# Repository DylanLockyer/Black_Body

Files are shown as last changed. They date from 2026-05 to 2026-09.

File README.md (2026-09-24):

# Black Body Controller
[USER MANUAL](Documentation/README.md)

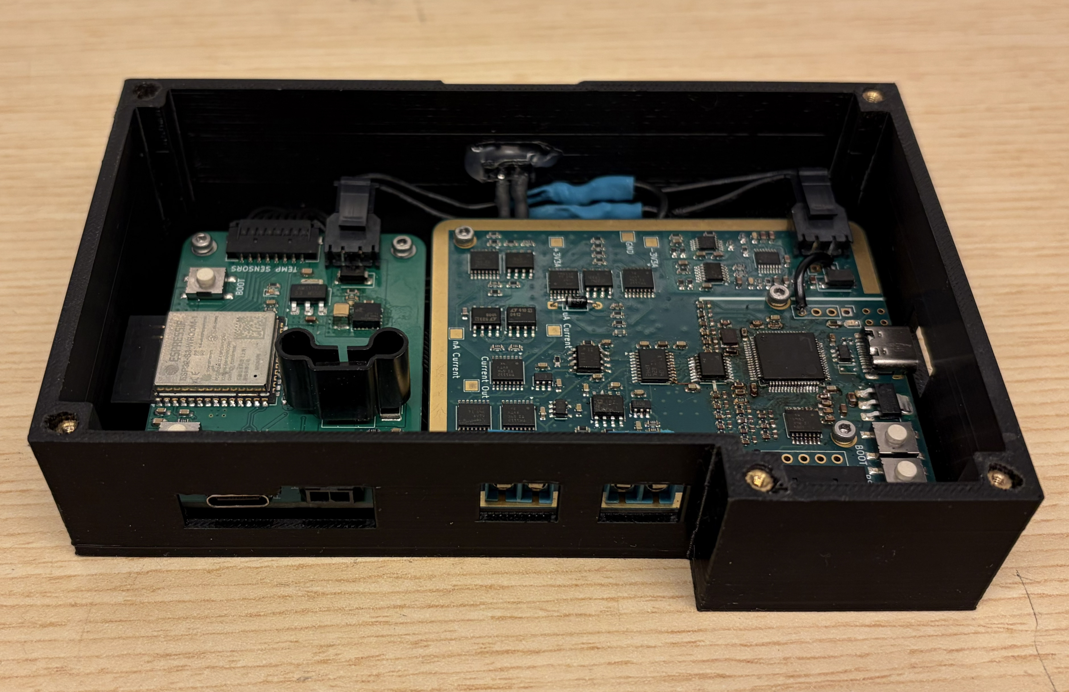
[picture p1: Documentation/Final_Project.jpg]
Measure tab

## Overview
This project controls and monitors a black body heater module mounted to the 4K stage of a cryostat. It is split into two custom PCBs: a heater control board built around an ESP32 (current source, voltage/current sensing, PID control, and a self-hosted web interface) and a temperature sensor board built around an STM32G4 for reading from a germanium temperature sensor for ranges from 0.3 to 100 kelvin (high-precision, low-noise excitation and readout for temperature probes). The two boards communicate over SPI, with the ESP32 acting as the master controller and network-facing interface.

## Project Goals
- Heat the black body module (4x 10Ω heaters in series, 40Ω equivalent) from the cryostat's 4K stage to temperatures above 80K, with closed-loop PID control.
- Accurately measure temperature across the cryogenic range using a Germanium RTD (LakeShore GR-300-AA).
- Provide low-noise, precisely switchable current excitation (10nA to 1mA) and high-resolution (24-bit) voltage/current measurement for sensor readout.
- Expose a self-hosted web interface (over WiFi) for live monitoring and control of both heating and measurement, with no external software required.

## Documentation
- [Heater Control PCB](Circuit%20Boards/Black_Body_Heater_Control_PCB/README.md) — heater current source, voltage/current sensing, and power supply design.
- [Temperature Sensor PCB](Circuit%20Boards/Black_Body_Temperature_Sensor_PCB/README.md) — sensor excitation, precision measurement, and isolation design.
- [ESP32 Firmware](Firmware/ESP32_heater/README.md) — heater PID control, SPI link to the sensor board, and the web interface.
- [STM32 Firmware](Firmware/stm32_black_body/README.md) — sensor excitation control, ADC readout, and the SPI link to the ESP32.
- [Device Usage Guide](Documentation/README.md) — how to power up, connect to, and operate the device.

## Repository Organization
**Circuit Boards:** KiCad source files and manufacturing/gerber files for both PCBs.

**Firmware:** ESP32 (PlatformIO) heater control firmware and STM32 (STM32CubeIDE) sensor readout firmware.

**Documentation:** Images, schematics, and the device usage guide.

**Simulations:** LTspice and PSpice simulations used to validate circuit designs before ordering.

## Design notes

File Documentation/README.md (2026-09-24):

# Device Usage Guide

How to power up, connect to, and operate the black body controller. For hardware/firmware design details, see the [root README](../README.md) and its links.

## Getting Started

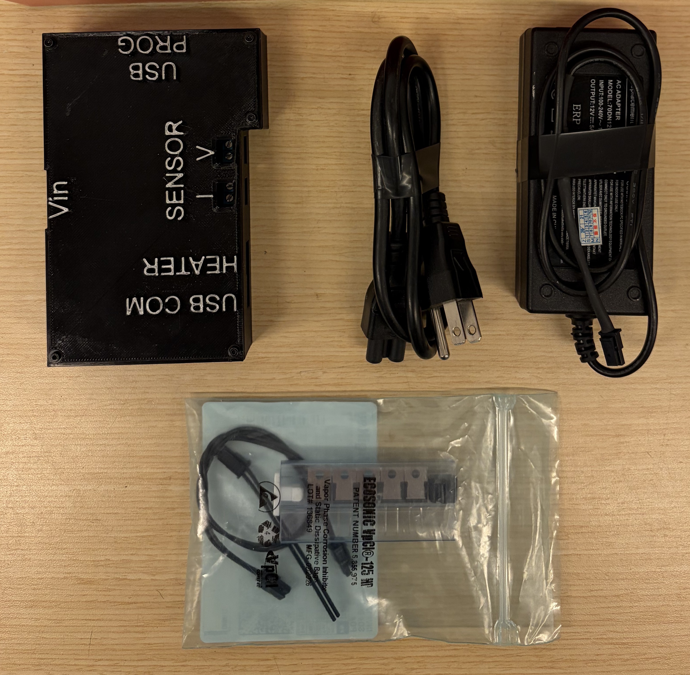
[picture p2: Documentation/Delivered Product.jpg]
Delivered Product


The delivered unit is the 3D-printed enclosure (containing both PCBs), a 12V AC power adapter with mains cable, and a bag with the temperature probes and cables.

The enclosure has five connections on its edges:

| Label | Purpose |
|---|---|
| **Vin** | 12V DC input from the included power adapter |
| **SENSOR — I / V** | 4-wire connection to the germanium temperature probe: the **I** terminals carry the excitation current, the **V** terminals are the voltage sense leads |
| **HEATER** | The resistive heater element (max 12V/0.5A) |
| **USB COM** | USB port to the ESP32 heater/control board |
| **USB PROG** | USB port to the STM32 sensor board |

Before powering on, connect the temperature probe to **SENSOR** (I and V screw terminals) using the probe's datasheet to match pinout and the heater to **HEATER**, then plug the power adapter's output into **Vin**. The USB ports are only needed when reprogramming the firmware (see [Programming](#programming)) — they aren't used for normal operation. For the first power up after delivery it is recommended to use a resistor connected via 4 wire kelvin sensing to the Sensor I/V to ensure it wasn't damaged in transit.

## Powering On

Plug the adapter into mains power. There is no separate power switch — connecting mains power turns the unit on, and unplugging it turns it off. On power-up, the ESP32 begins broadcasting its WiFi access point and the STM32 sensor board starts pushing resistance/voltage/current readings to it over SPI; the readings become live in the web interface within a few seconds.

## Connecting to the Device

The controller hosts its own WiFi network — it does not join your existing WiFi. Connect to the access point:

- **Network name:** `Black Body`
- **Password:** none (open network)

Most phones and laptops will detect the captive portal and open the control page automatically. If it doesn't pop up, open a browser and go to:

```
http://192.168.4.1/
```

## Using the Web Interface

### Measure

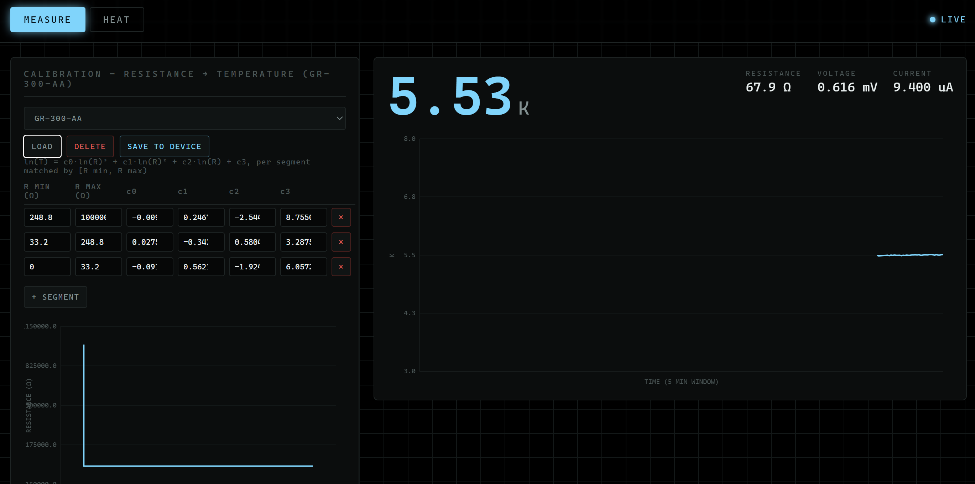
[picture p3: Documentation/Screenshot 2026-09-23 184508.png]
Measure tab


The left panel manages calibration **profiles** for the connected sensor: the default profile for the GR-300AA is automatically loaded. To pick a different saved profile, select it from the dropdown and use **LOAD** to make it active, **SAVE TO DEVICE** to store the currently-edited segments under a name, or **DELETE** to remove a saved profile. The segment table below it defines the resistance-to-temperature curve as a set of piecewise cubic segments (see [Calibration](#calibration) for how these are generated); use **+ SEGMENT** to add a row. The **DEBUG** panel (click **SHOW**) exposes the current excitation level, current direction, active shunt resistor, whether the calibration is valid, and which profile is currently active.

The right panel shows the live reading: temperature in large text, with resistance, voltage, and current underneath, plus a rolling 5-minute chart.

### Heat

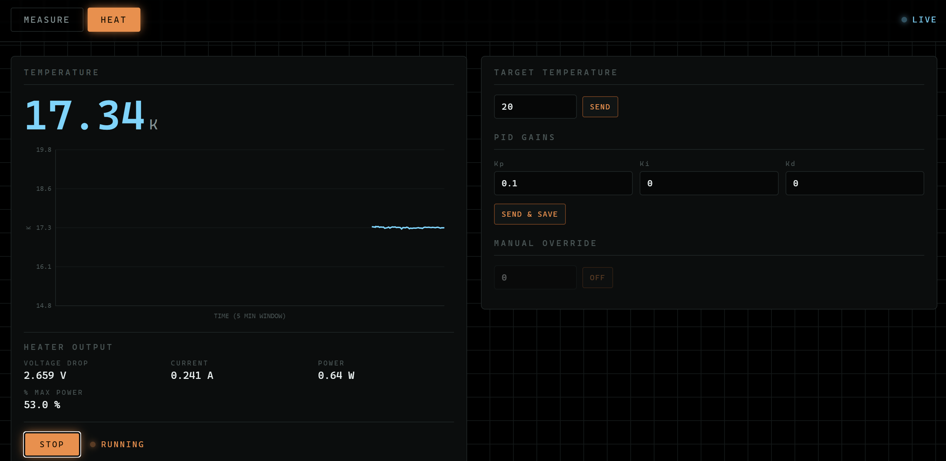
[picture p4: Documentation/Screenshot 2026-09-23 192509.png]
Heat tab


The left panel shows live temperature and a chart, plus a heater output readout (voltage drop, current, power, and percent of max power), and the **START/STOP** button that enables or disables closed-loop control.

The right panel sets the **target temperature** (sent with **SEND**) and the **PID gains** Kp/Ki/Kd (sent and saved to flash with **SEND & SAVE**). A **manual override** lets you drive the heater at a fixed current (0–0.5A) instead of running PID for testing which only works while the PID loop is stopped; the device will reject it otherwise.

## Calibration

Calibration profiles map measured sensor resistance to temperature as piecewise cubic segments of the form:

```
ln(T) = c0·ln(R)³ + c1·ln(R)² + c2·ln(R) + c3
```

with each segment applying over its own `[R min, R max)` range.

There are two ways to get the data for a new profile:

- **From the sensor's datasheet:** most calibrated sensors, including LakeShore probes, come with a resistance-vs-temperature table or published fit coefficients for that specific sensor. Use those values as the (resistance, temperature) pairs in step 3 below and skip the measurement steps. If the datasheet already gives piecewise fit coefficients in the same `ln(T)` vs `ln(R)` form, you can enter them directly (step 4).
- **By measuring the sensor yourself:** follow all the steps below.

To build a new profile for a sensor:

1. On the **Measure** tab, read the live resistance value as you take the probe through its usable temperature range (e.g. warming or cooling it slowly while checking its temperature against a reference).
2. Record pairs of (resistance, temperature) at enough points to span the full range you care about.
3. Give this list of resistance/temperature pairs to an AI assistant (e.g. Claude) and ask it to fit the data to the segmented curve form above, i.e. to return the `[R min, R max)` bounds and `c0`–`c3` coefficients for each segment needed to cover your data.
4. Enter the returned segments into the segment table on the Measure tab (use **+ SEGMENT** to add rows), then click **SAVE TO DEVICE** and give the profile a name.
5. Select the new profile from the dropdown and **LOAD** it to make it active.

## Programming

Reflashing either board requires opening the enclosure:

1. Unplug the power adapter, then remove the 5 M2 screws holding the enclosure lid and lift it off to access the boards' USB ports and BOOT/RESET buttons.
2. Reconnect the 12V power supply to **Vin**, and connect a USB cable from your PC to the port for the board you're programming — **USB COM** for the ESP32, **USB PROG** for the STM32.
3. On that board, hold down its **BOOT** button, briefly press and release **RESET**, then release **BOOT**. This forces the microcontroller into its USB bootloader instead of starting the existing firmware.
4. Flash the new firmware:
   - **ESP32** ([`Firmware/ESP32_heater`](../Firmware/ESP32_heater)): build and upload with PlatformIO (`pio run -t upload`, or the Upload button in the PlatformIO IDE). If you changed `data/website.html`, also run `pio run -t uploadfs` to update the web UI stored on the device.
   - **STM32** ([`Firmware/stm32_black_body`](../Firmware/stm32_black_body)): build using stm32 extension for VScode + cmake and flash with STM32CubeProgrammer over the USB PROG connection.
5. Unplug the unit, replace the lid, and reinstall the 5 M2 screws.

## Specifications

| | |
|---|---|
| **Input power** | 12V DC, via included adapter into **Vin** |
| **Heater element** | 4×10Ω in series (40Ω), analog current-source driven (not PWM) |
| **Heater output** | Up to ~12V / 0.3A peak, ~10W max |
| **Heater control** | Closed-loop PID, or manual current override (0–0.5A) while PID is stopped |
| **Sensor excitation current** | 10nA – 1mA DC in six decade steps (10nA, 100nA, 1µA, 10µA, 100µA, 1mA), switchable polarity |
| **Sensor ADC** | 24-bit (ADS131M04) |
| **Supported sensor** | LakeShore GR-300-AA germanium RTD, 4-wire |
| **Temperature range** | 2K – 100K. The GR-300-AA is rated down to 0.3K, but the low-temperature excitation limiting needed below ~2K was never calibrated, so that range is disabled |
| **Wireless interface** | Self-hosted WiFi AP `Black Body` (open), captive portal, `192.168.4.1` |
| **Board-to-board link** | SPI (ESP32 as slave, STM32 as master) |
| **Microcontrollers** | ESP32-S3 (heater/control board), STM32G431 (sensor board) |
| **Programming** | USB COM → ESP32 (PlatformIO), USB PROG → STM32 (STM32CubeProgrammer) |

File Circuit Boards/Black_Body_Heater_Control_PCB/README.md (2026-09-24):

# Black Body Heater Control PCB

Two-layer circuit board carrying the ESP32 microcontroller and all heater control electronics: current source, voltage/current sensing, and power supply. See the [firmware README](../../Firmware/ESP32_heater/README.md) for how this board is driven, and the [root README](../../README.md) for overall project context.

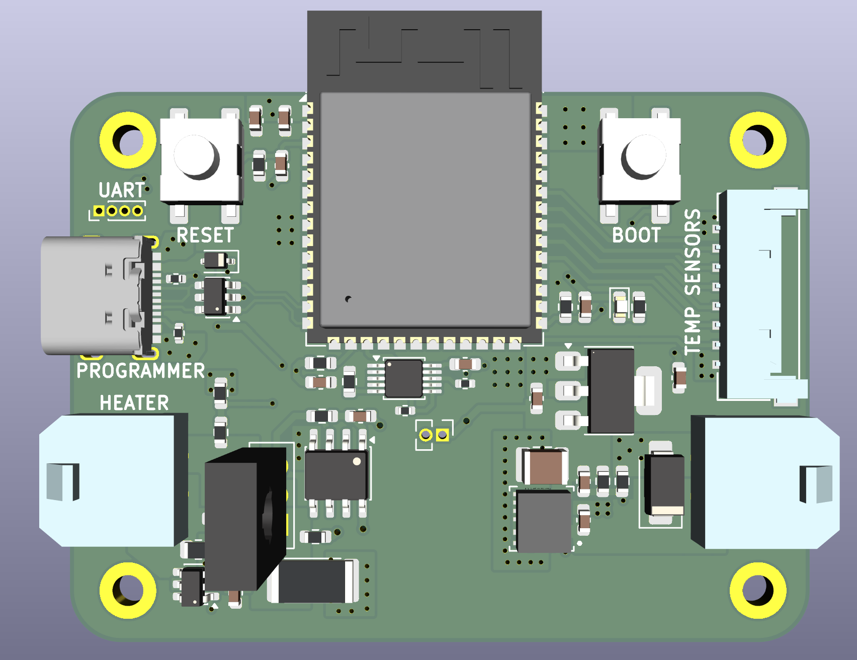
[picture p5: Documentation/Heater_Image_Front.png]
Front

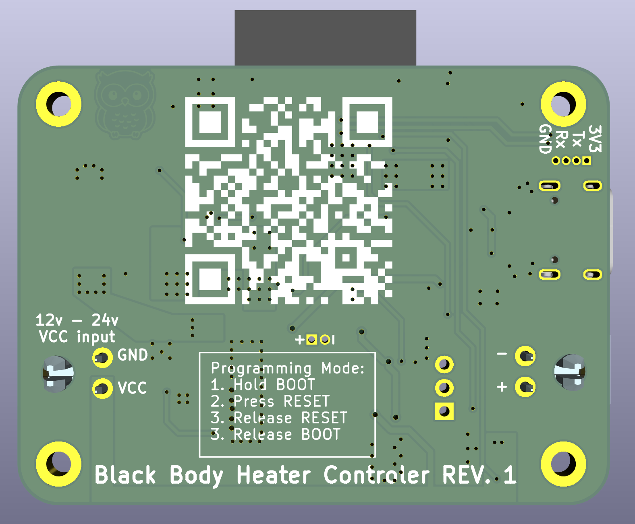
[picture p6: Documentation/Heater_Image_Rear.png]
Rear


Schematic: [Black_Body_Heater_Control_Schematic.pdf](../Black_Body_Heater_Control_Schematic.pdf)

## Microcontroller
An ESP32 was chosen for its high pin count and WiFi support, letting it self-host a web page for displaying readings and controlling the heater. It interfaces with the [temperature sensor board](../Black_Body_Temperature_Sensor_PCB/README.md) over SPI (3 CS lines for 3 temperature probes). The microcontroller is programmed over USB, with exposed pads for UART programming as a fallback. Board-to-board interfacing uses Molex connectors (504050-0891 for the SPI link) since they could be sampled for free.

## Heater Controller
The heater is 4x 10Ω resistors in series (40Ω total). A maximum output power of 10W requires a peak 12V at 0.3A, measured with a shunt resistor + amplifier (current) and a voltage divider (voltage), both read by the ESP32's internal 12-bit ADC. This gives a theoretical current step of 100µA (max 0.66A range) and a voltage step of 8mV (max 36V range).

The original design used an N-channel MOSFET with PWM to control heater voltage. Due to concerns about PWM noise interfering with the sensor board's measurements, this was replaced with an analog current source instead.

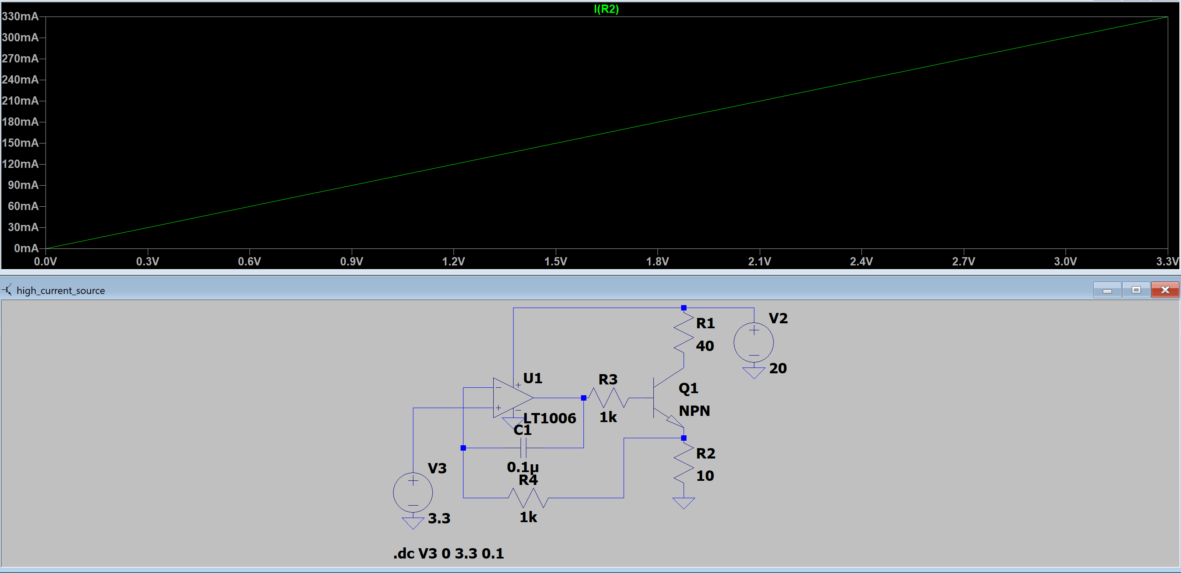
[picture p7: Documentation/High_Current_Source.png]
High Current Source


Output current vs. input voltage for the analog current source. A BJT and op-amp generate the current output, driven by a DAC that the microcontroller controls.

## Shunt Current Measurement
The shunt resistor is 100mΩ with a 50V/V amplifier gain, giving 2.5V output at 0.5A and 0.25V at 0.05A. A low-pass filter on the amplifier output is largely unnecessary now that PWM isn't used, but is kept (with an easy jumper to bypass it) in case it's needed. Simulated filtering of a 10% duty cycle, 10kHz PWM signal on 20V is shown below:

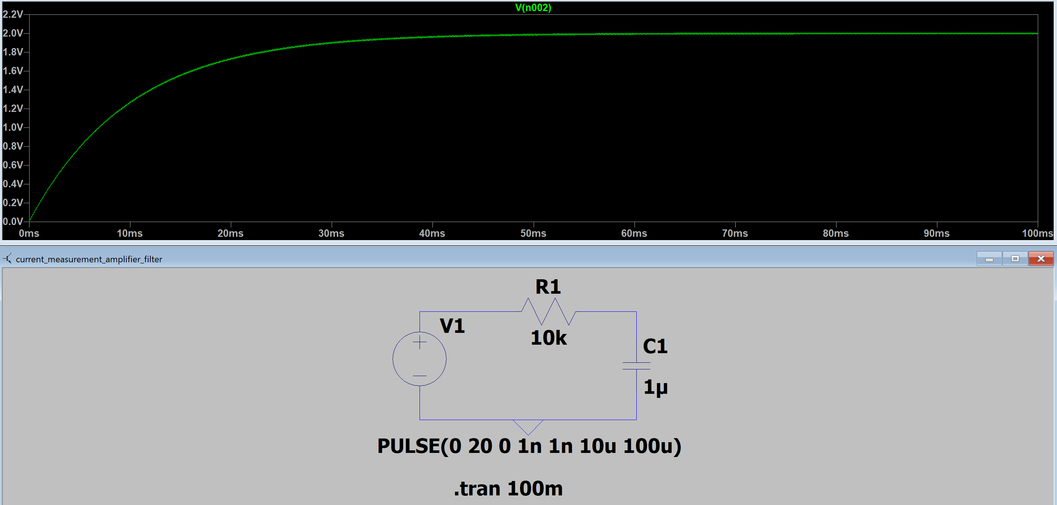
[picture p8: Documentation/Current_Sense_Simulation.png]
Current Sense Simulation


## Power Source
The board receives 12V from an external power supply. A buck converter steps this down to 5V at 2A, followed by an LDO to 3.3V for a clean, low-noise supply to the microcontroller and ADC. \
**Revision 1:** Changed buck converter to newer module as the rev 0 as it broke and fried both boards.

## Simulation
Heater and buck converter behavior were validated in PSpice before layout (see [Simulations/Heater_Controller_PCB](../../Simulations/Heater_Controller_PCB)):

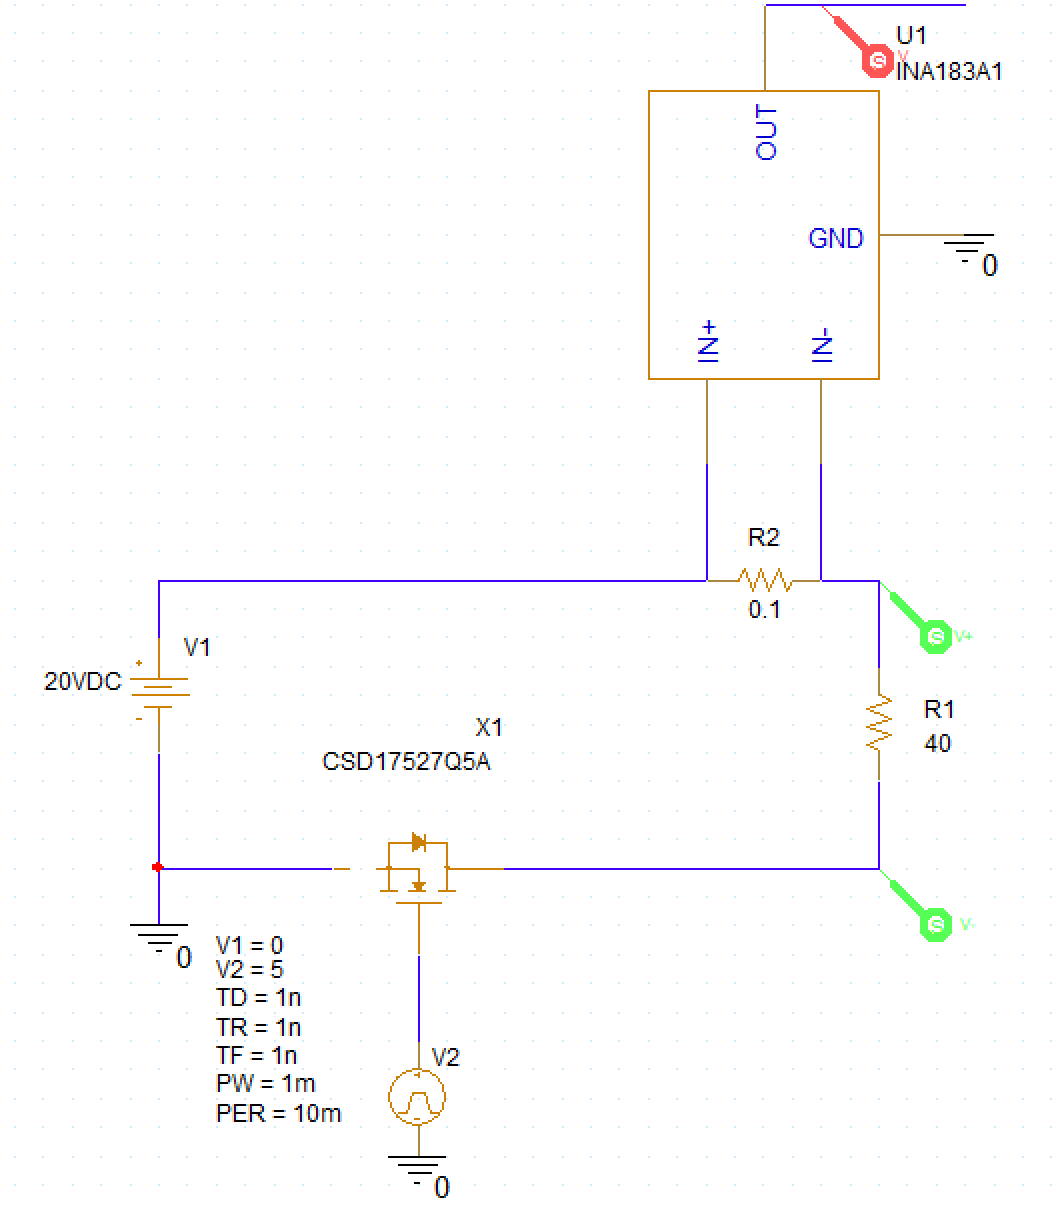
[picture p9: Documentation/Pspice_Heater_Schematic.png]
PSpice Heater Schematic

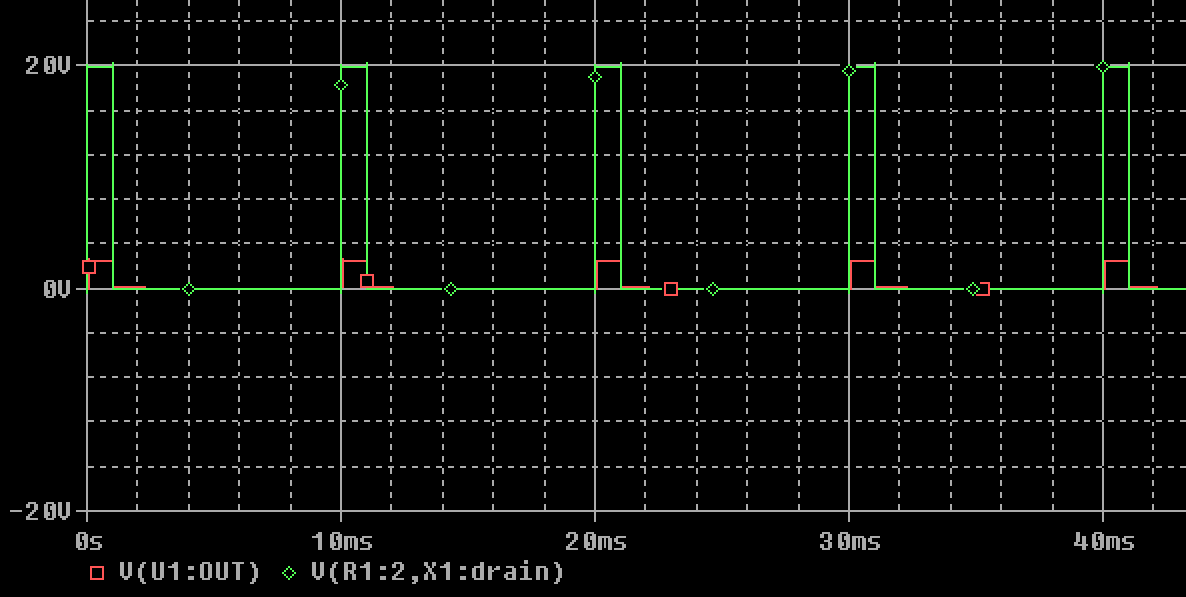
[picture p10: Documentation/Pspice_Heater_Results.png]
PSpice Heater Results


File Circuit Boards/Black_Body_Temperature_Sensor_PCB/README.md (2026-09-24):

# Black Body Temperature Sensor PCB

Six-layer circuit board that reads temperature from Germanium RTD sensors and Silicon diode sensors. See the [firmware README](../../Firmware/stm32_black_body/README.md) for how this board is driven, and the [root README](../../README.md) for overall project context.

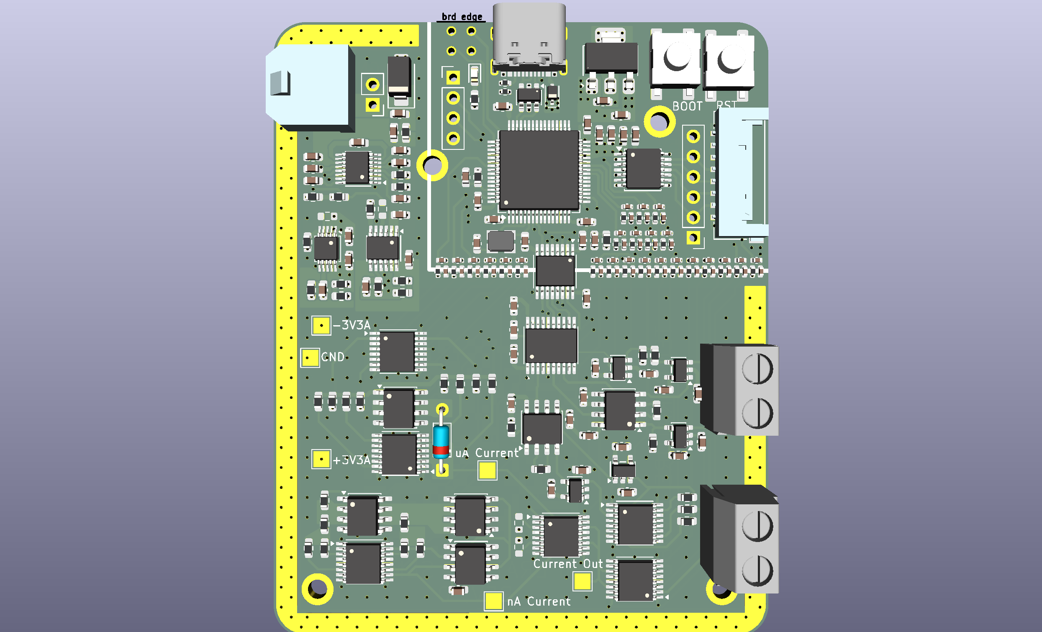
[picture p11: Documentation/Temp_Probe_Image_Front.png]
Front

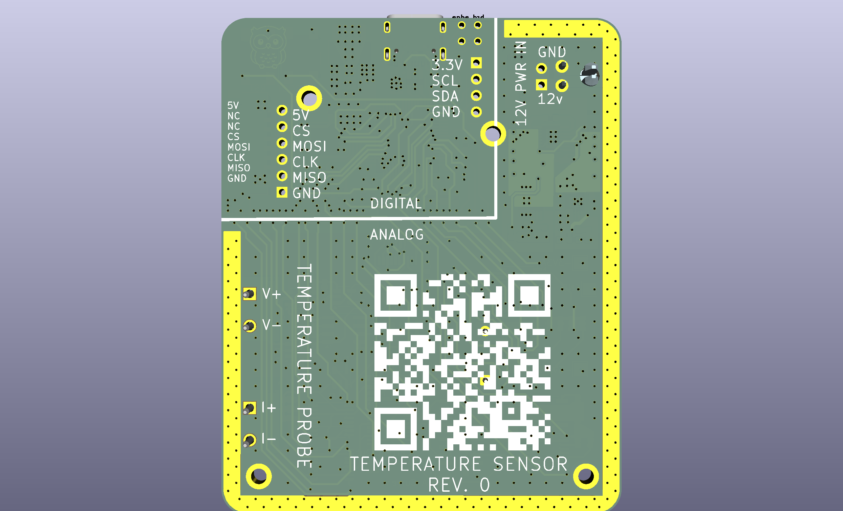
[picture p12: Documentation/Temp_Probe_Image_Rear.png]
Rear


Schematic/board renders: [Black_Body_Temperature_Sensor_Schematic.pdf](../../Documentation/Black_Body_Temperature_Sensor_Schematic.pdf), [Black_Body_Temperature_Sensor_PCB.pdf](../../Documentation/Black_Body_Temperature_Sensor_PCB.pdf)

## Temperature Probe Readers
The board must support both Germanium sensors (LakeShore GR-300-AA) and Silicon diode sensors (LakeShore DT-670A1-CU), which are both 4-wire sensors: current is sourced over 2 wires (I+/I-) and voltage is read over the other 2 (V+/V-) so the voltage drop across the lead wires isn't included in the measurement.

Two LakeShore temperature probe readers were used as reference:

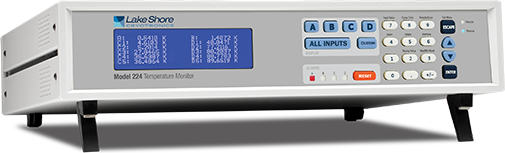
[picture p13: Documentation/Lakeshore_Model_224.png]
Lakeshore Model 224

**Model 224:** Accurate to 0.3K with DC current from 100nA to 1mA. Ability to source both positive and negative current allows EMF voltages to be eliminated.

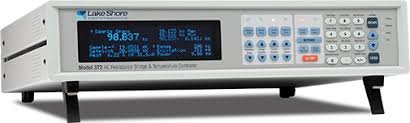
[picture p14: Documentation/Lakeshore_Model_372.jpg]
Lakeshore Model 372

**Model 372:** Accurate to 0.05K with AC current as low as 10pA to eliminate self-heating at extremely low temperatures (power levels in attowatts, 10⁻¹⁸W). Significantly more complex to implement and unnecessary for our sensors, which don't go below 0.3K.

The Model 224 was used as the primary reference since this application won't go below 4K, and it supports almost the full range of the GR-300-AA and the full range of the DT-670A1-CU (down to 1.4K).

## DT-670A1-CU Sensor
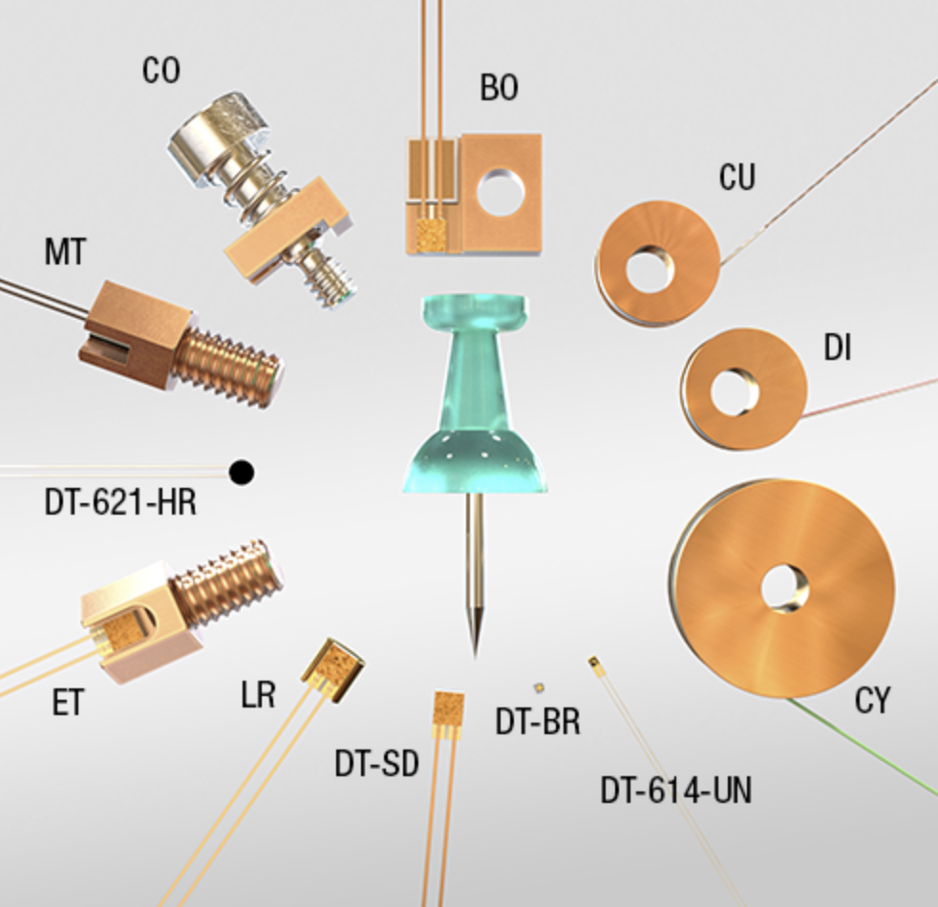
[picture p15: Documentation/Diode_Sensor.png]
Diode Sensor

Silicon diode temperature sensor, 1.4K to 420K range. Requires a constant excitation of 10µA ± 0.1%; the voltage across it ranges from 1.64V at 1.4K to 0.560V at 305K.

## GR-300-AA Sensor
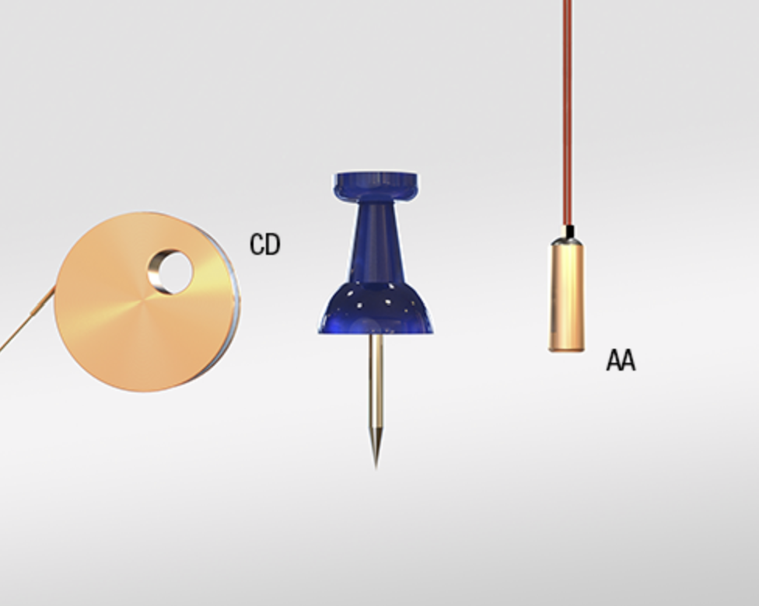
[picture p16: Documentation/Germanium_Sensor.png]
Germanium Sensor

Germanium temperature sensor, 0.3K to 100K range. Resistance varies logarithmically with temperature, from 35180Ω at 0.3K to 2.716Ω at 100K. Below 1K, excitation should be limited (LakeShore recommends 63µV; the Model 224 uses 3600µV at 0.3K to 900µV at 1K) since thermal mass is very small and self-heating matters more. Above 1K, excitation should stay under 10mV; the Model 224 sources 100nA to 1mA to keep the voltage under that limit.

## My Implementation
- Current excitation from 10nA to 1mA, DC, switchable direction.
- High-precision instrumentation amplifier for I+/I- sensor lead current measurement.
- Voltage measurement precise across 1mV to 10mV, since below 1K the signal can't go lower than ~0.9mV (10nA) and above 1K self-heating matters less.
- 24-bit ADC for both current and voltage; galvanic isolation between the digital and analog side is manually bypassed as it was causing issues and the same power supply is used for both digital and analog sides.
- Low-noise, high common-mode-rejection amplifiers to bring small signals up to reasonable voltage levels.

## Clean Voltage Supply
The board takes in a clean +12V, low-pass filtered. An LTC3260 splits the rail into +5V and -5V. The +5V rail is regulated to +3.3V with an LT3042EMSE, and the -5V rail similarly with an LT3094, for extra-clean supplies.

The LTC3260 could not be simulated (a common issue with its SPICE model), but the 3.3V regulator stages were simulated:

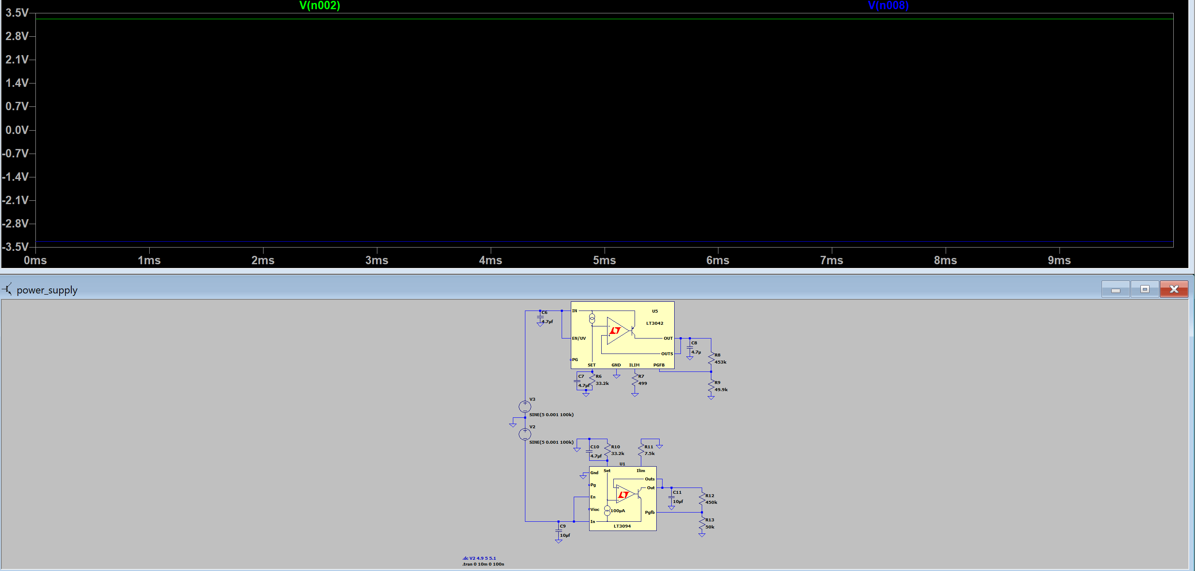
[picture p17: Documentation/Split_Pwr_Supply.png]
Split Power Supply


## Current Sources
Target outputs: 10nA, 100nA, 1µA, 10µA, 100µA, 1mA, split into two circuits (below 1µA and above/equal to 1µA).

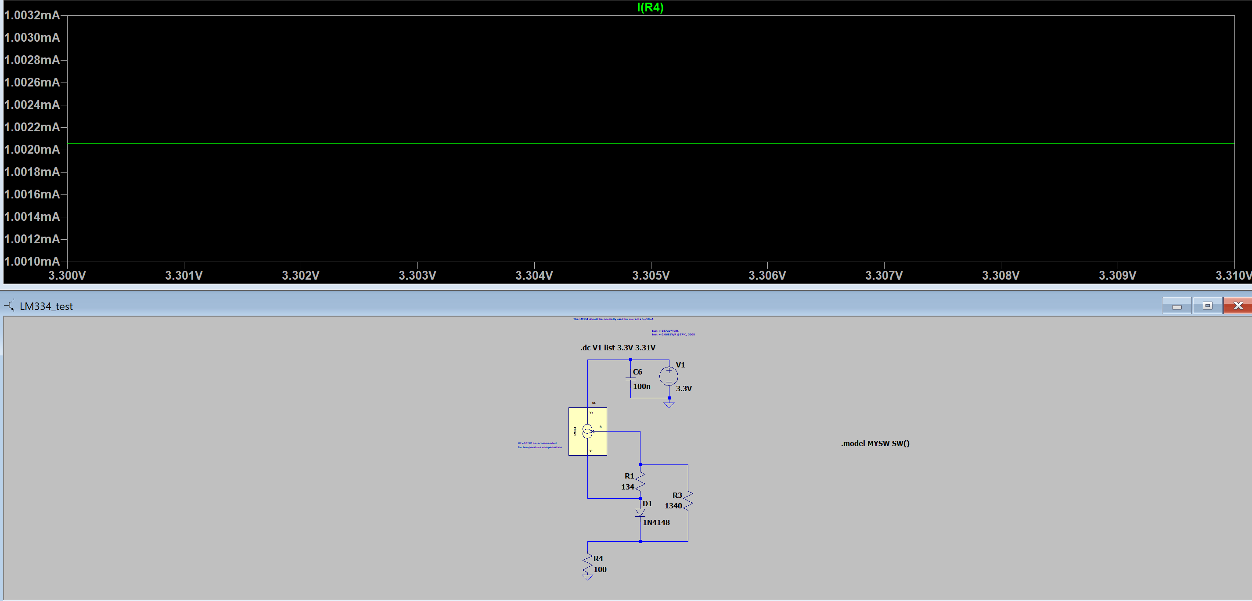
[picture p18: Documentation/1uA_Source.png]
1uA Source

Greater-than-1µA source, using the TI LM334 per its application note. Different current outputs are selected by switching resistors R1 & R3 with high-precision analog switches.

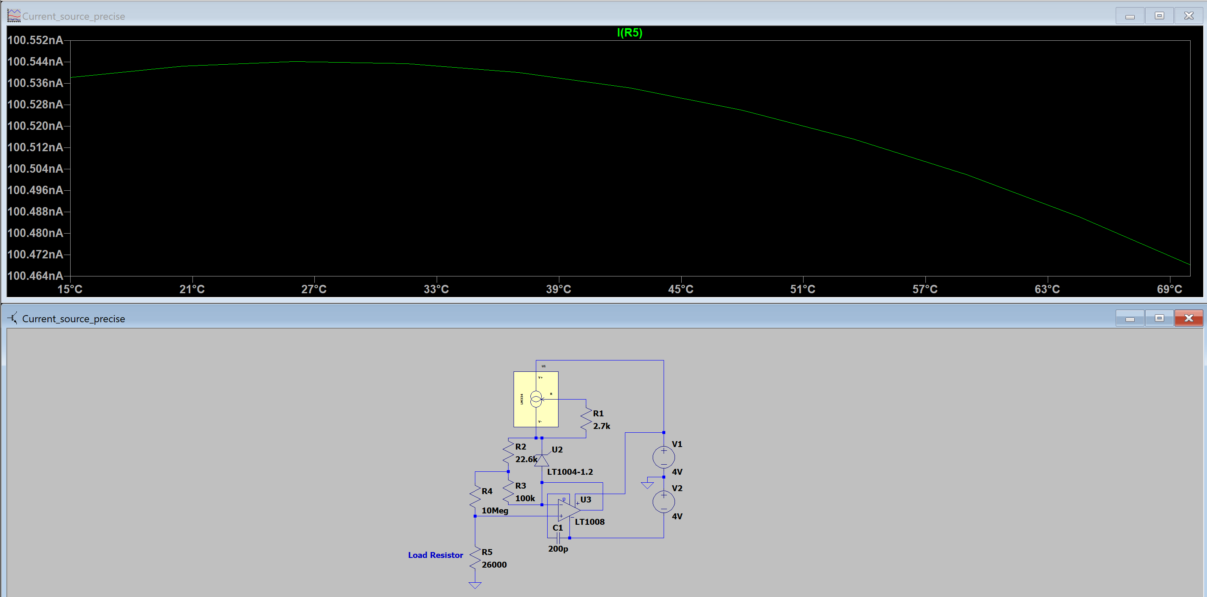
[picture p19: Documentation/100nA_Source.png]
100nA Source

Less-than-1µA source, also using the LM334 but following an Analog Devices example schematic with an instrumentation op-amp to reach the 10nA range (confirmed by simulation). Analog switches again select the current level.

## Voltage Measurement
The Germanium sensors produce 0.5mV to 5mV at the given excitation currents. The signal is buffered by an OPA376 (10pA bias current), then fed to a differential instrumentation amplifier (AD8421ARZ, 200x gain), then into one of the 4 channels of a 24-bit ADC (ADS131M04). The ADC communication is isolated from the microcontroller to keep the analog and digital grounds separate.

## Current Measurement
Measured via the shunt method, using the same voltage-measurement chain to read the voltage drop across a 5Ω, 500Ω, or 33kΩ shunt (selected with analog switches).

## Switching Current Direction
The same analog switches (TMUX1112PWR, 3pA noise injection) reverse current direction between measurements to cancel out EMF voltages induced by dissimilar metals in the sensor leads.

## Digital Section
Built around the STM32G4. It has a 5V-tolerant SPI interface for talking to the [heater control board](../Black_Body_Heater_Control_PCB/README.md), and a USB 2.0 interface for programming and future use with a PC application. Either connection can supply power, with protection against both being connected simultaneously. An I2C breakout is provided for future expansion. All GPIOs driving the analog-section switches pass through a PI filter first to give a slow ramp-up and limit noise:

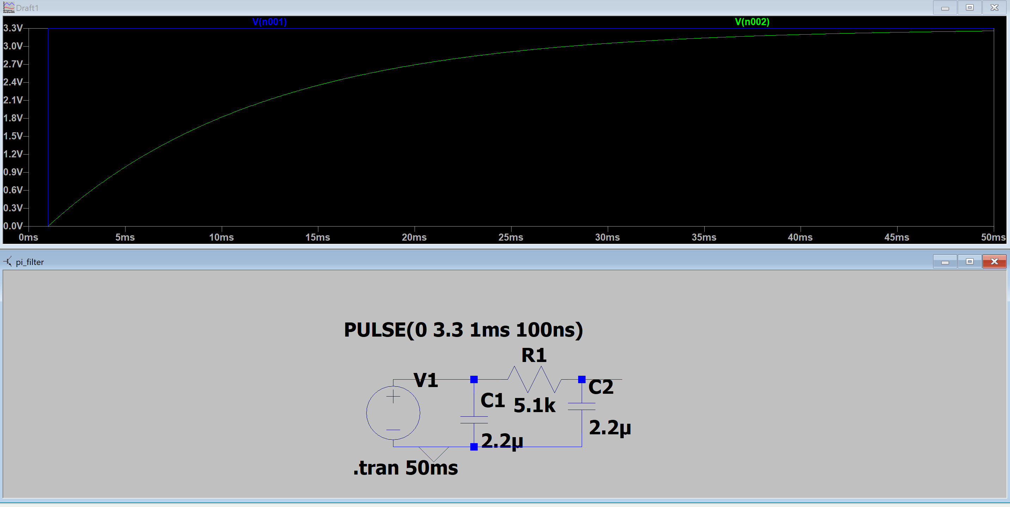
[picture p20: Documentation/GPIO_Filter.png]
GPIO Filter


## Stackup
Six layers, chosen to simplify grounding, with ENIG surface finish:

```
Analog
Gnd
+3.3V
-3.3V
Gnd
Mixed signal
```

The two 3.3V layers also carry small digital 3.3V and GND traces to the analog switches. The bottom layer is primarily digital switch routing, with some small analog jumps.

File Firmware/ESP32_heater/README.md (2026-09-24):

# ESP32 Heater Firmware

Firmware for the [heater control PCB](../../Circuit%20Boards/Black_Body_Heater_Control_PCB/README.md). Built with PlatformIO (Arduino framework for ESP32). This is the "master" of the system: it drives the heater, talks to the STM32 sensor board over SPI, and hosts the web interface used to operate the device — see the [device usage guide](../../Documentation/README.md).

## What It Does
- **WiFi access point + web UI:** Starts a self-hosted WiFi AP (`WiFi.softAP`) with a DNS captive portal and an async web server that serves the control page (`data/website.html`) and a JSON API for live readings and commands.

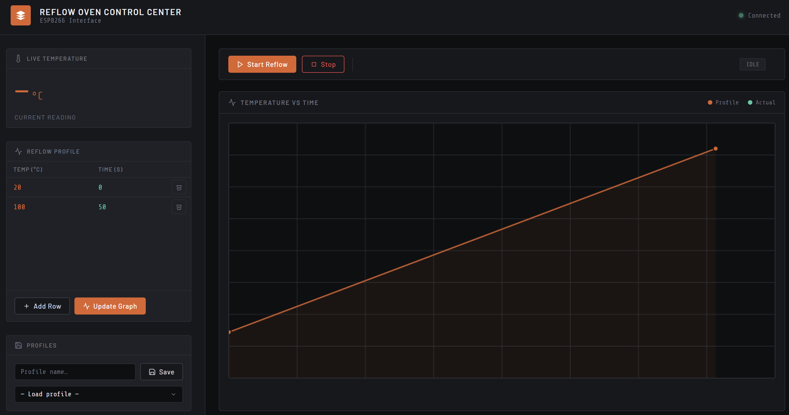
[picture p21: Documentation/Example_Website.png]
Example UI
  

- **Sensor readout over SPI:** Acts as an SPI slave, receiving voltage/current/resistance readings (`STM32Sensor`) pushed by the STM32 sensor board, which drives the SPI clock as master.
- **Resistance → temperature calibration:** Maintains per-sensor calibration "profiles" (piecewise cubic segments mapping resistance to temperature, see `SegmentedCalibration.h`), editable from the web UI and persisted to flash (LittleFS) so no on-device curve fitting is needed.
- **Heater PID control:** Runs a PID loop targeting a user-set temperature, or a manual power override, and drives the heater's analog current source through a DAC (`DAC60501`). PID gains and the active setpoint are persisted to flash.

## Task Structure
The firmware splits work across the ESP32's two cores to keep the SPI link and WiFi stack from blocking each other:
- **Core 0 — `sensorTask`:** Polls the STM32 over SPI as fast as possible and updates the shared reading state under `dataMutex`.
- **Core 1 — `loop()`:** Arduino's main loop, handling only WiFi/DNS captive-portal housekeeping.
- **Core 1 — `heaterTask`:** Runs the PID/manual-override heater control loop at ~5Hz, independent of the networking loop.

## Layout
- `src/main.cpp` — setup, FreeRTOS tasks, PID control, calibration/config persistence.
- `include/main.h` — pin definitions and shared types.
- `data/website.html` — the web UI served to clients connected to the AP.

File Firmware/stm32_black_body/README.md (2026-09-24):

# STM32 Temperature Sensor Firmware

Firmware for the [temperature sensor PCB](../../Circuit%20Boards/Black_Body_Temperature_Sensor_PCB/README.md), targeting an STM32G431. Built with STM32CubeIDE / CMake (STM32CubeMX-generated HAL project). This board does the precision analog work — sourcing current into the sensor and reading it back — and pushes the result to the [ESP32](../ESP32_heater/README.md) for display and control.

## What It Does
- **Current source control:** `change_current()` selects the excitation current level and direction (10nA to 1mA, switchable polarity) by driving the analog switches on the sensor board.
- **External ADC readout:** Reads the 24-bit ADS131M04 ADC over SPI3 whenever its DRDY interrupt fires (`adc_flag`), capturing both the sensor voltage and the shunt voltage (used to derive current) for whichever shunt resistor (5Ω / 500Ω / 33kΩ) is currently selected.
- **Resistance calculation:** Computes sensor resistance from the averaged voltage and current readings (a rolling average smooths ADC noise before the divide).
- **Auto-ranging:** `autoset_current()` checks whether the current reading is in a good range for the selected sensor and switches current level/shunt automatically if not.
- **Push to ESP32:** Sends the latest voltage/current/resistance reading to the ESP32 over SPI2, with this board acting as SPI *master* (the ESP32 is the SPI slave and receives whatever this board clocks out).
- **USB:** USB 2.0 (`MX_USB_PCD_Init`) is used for programming and is reserved for a future PC-side application. Either USB or the ESP32 connector can supply board power, with protection against both being connected at once.
- **I2C:** Broken out for future expansion; unused by the current firmware logic.

## Layout
- `Core/Src/main.c` — peripheral init, the ADC read/current-switching main loop, and the SPI push to the ESP32.
- `Library/External_Interface` — SPI2 send routine used to talk to the ESP32.
- `Library/ADS131M04` — Communicates with SPI to the 24-bit adc.

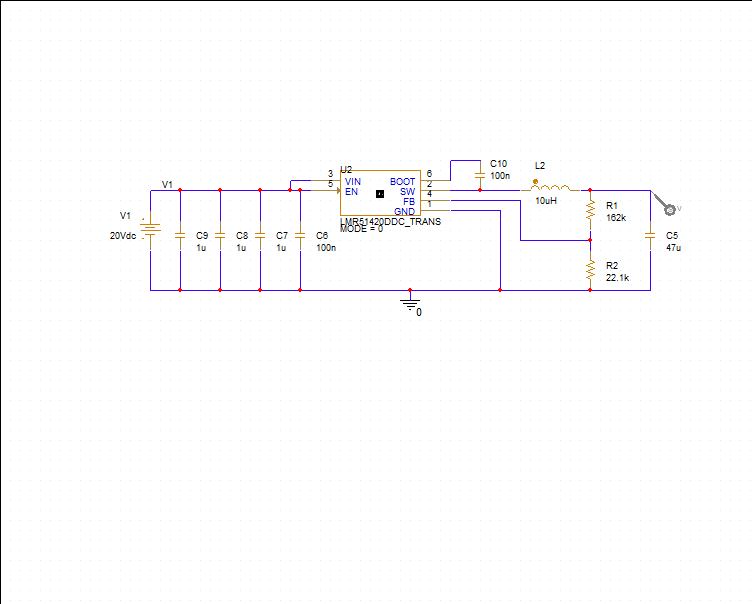
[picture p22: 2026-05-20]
Simulations/Heater_Controller_PCB/Pspice_buck/PSPICE_BUCK.png

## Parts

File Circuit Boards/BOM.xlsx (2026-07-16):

Designator | Footprint | Quantity | Value | LCSC Part #
C201, C202, C203, C204, C205, C206, C207, C208, C209, C210, C211, C212, C213, C214, C215, C216, C301, C302, C303, C304, C305, C306, C307, C308, C401, C402, C403, C404, C405, C406, C407, C408, C409, C410, C411, C412, C413, C414, C415, C416, C417, C418, C419, C420, C421, C422, C423, C424 | 0402 | 48 | 2u2 | GRM155R61E225ME15D
C309 | 0603 | 1 | 200pf | CL10C201JB8NNNC
C501 | 0603 | 1 | 220nf | GCM188R71H224KA64D
C502, C503, C504, C505, C506, C507, C508, C509, C510, C511, C512, C513, C514, C515, C516, C517, C518, C519, C701, C702, C704, C706, C707, C708, C709, C710, C711, C713, C714 | 0603 | 29 | 0.1uf | CL10B104KB8NNNC
C601, C602, C606, C607, C609, C614, C615, C712 | 0603 | 8 | 10uf | GRM188R6YA106MA73D
C603 | 0603 | 1 | 1uf | C0603C105K4RACTU
C604, C605 | 0603 | 2 | 10nf | CL10B103KB8NNNC
C608, C610, C611, C612, C613 | 0603 | 5 | 4.7uf | CL10A475KO8NNNC
C703, C705 | 0603 | 2 | 28pf | CL10C270JB8NNNC
C715 | 0603 | 1 | 22uf | CL10A226MP8NUNE
D201 | D_DO-35_SOD27_P7.62mm_Horizontal | 1 | 1N457 | 1N457
D301 | SOIC-8_3.9x4.9mm_P1.27mm | 1 | LT1004-1.2 | LT1004CS8-1.2#TRPBF
D601 | D_SMA | 1 | SMAJ24A | SMAJ24A
D701 | D_SOD-323 | 1 | 1N5819WS | 1N5819WS
J401, J402 | CUI_TB002-500-02BE | 2 | Screw_Terminal_01x02 | TB002-500-02BE
J702 | CONN_5040500891_MOL | 1 | 5040500891 | 5040500891
J703 | UJ20-C-H-G-SMT-1-P16-TR | 1 | USB_C_Receptacle_USB2.0_16P | UJ20-C-H-G-SMT-1-P16-TR
P601 | 436500200 2-pin | 1 | 436500200 | 436500200
Q201, Q202, Q301, Q401, Q402, Q403 | TSSOP-16_4.4x5mm_P0.65mm | 6 | TMUX1112PWR | TMUX1112PWR
R201, R202, R203, R204, R205, R206, R207, R208, R301, R302, R303, R304, R401, R402, R403, R404, R408, R409, R410, R411, R414, R415, R416, R417, R701, R702 | 0402 | 26 | 5.1k | RT0402BRD075K1L
R209 | 0603 | 1 | 133 | RQ73C1J133RBTD
R210, R211 | 0603 | 2 | 1.33k | ERA-3AEB1331V
R212, R213 | 0603 | 2 | 13.3k | ERA-3AEB1332V
R214, R215 | 0603 | 2 | 134k | ERA-3AEB1333V
R216 | 0603 | 1 | 1.33M | RK73H1JTTD1334F
R305, R502, R504 | 0603 | 3 | 10M | CRCW060310M0DHEAP
R306 | 0603 | 1 | 22.6k | ERA-3AEB2262V
R307 | 0603 | 1 | 100k | ERA-3AEB104V
R308 | 0603 | 1 | 100M | HVC0603T1006FET
R309 | 0603 | 1 | 226k | ERA-3AEB2263V
R310 | 0603 | 1 | 1M | RN73H1JTTD1004B25
R311 | 0603 | 1 | 2.7k | ERA-3AEB272V
R405 | 0603 | 1 | 4.99 | RN73C1J4R99BTD
R406, R606, R616 | 0603 | 3 | 500 | ERA-3AEB4990V
R407, R605, R608 | 0603 | 3 | 33.2k | ERA-3AEB3322V
R412, R413, R505, R506, R703, R704 | 0603 | 6 | 10k | ERA-3AEB103V
R501, R503 | 0603 | 2 | 50 | ERA-3AEB49R9V
R601, R604 | 0603 | 2 | 569k | RN73H1JTTD5693B50
R602, R603, R607, R609 | 0603 | 4 | 180k | ERA-3AEB184V
R610 | 0603 | 1 | 7.5k | ERA-3AEB752V
R611, R613 | 0603 | 2 | 448k | RT0603BRD07448KL
R612, R614 | 0603 | 2 | 50k | RT0603BRD0750KL
SW701, SW702 | 430471035826 | 2 | SW_MEC_5E | 430471035826
U201, U301 | SOIC-8_3.9x4.9mm_P1.27mm | 2 | LM334M | LM334M
U302 | SOIC-8_3.9x4.9mm_P1.27mm | 1 | LT1008 | LT1008S8#PBF
U501, U502, U503, U504, U509 | SOT-23-5 | 5 | OPA376xxDBV | OPA376AIDBVR
U505, U506 | SOIC-8_3.9x4.9mm_P1.27mm | 2 | AD8421ARZ | AD8421ARZ
U507 | TSSOP-20_4.4x6.5mm_P0.65mm | 1 | ADS131M04xPW | ADS131M04IPWR
U508 | SSOP-16_3.9x4.9mm_P0.635mm | 1 | ISO7762FDBQ | ISO7762FDBQ
U601 | MSOP-16-1EP_3x4.039mm_P0.5mm_EP1.651x2.845mm | 1 | LTC3260xMSE | LTC3260EMSE#TRPBF
U602 | MSOP-12-1EP_3x4.039mm_P0.65mm_EP1.651x2.845mm | 1 | LT3094xMSE | LT3094EMSE#TRPBF
U603 | MSOP-10-1EP_3x3mm_P0.5mm_EP1.68x1.88mm | 1 | LT3042xMSE | LT3042EMSE#TRPBF
U701 | TSSOP-14_4.4x5mm_P0.65mm | 1 | TXU0304 | TXU0304
U702 | ABM8G-25.000MHZ-18-D2Y-T | 1 | ABM8G-25.000MHZ-18-D2Y-T | ABM8G-25.000MHZ-18-D2Y-T
U703 | SOT-23-6 | 1 | USBLC6-2SC6 | USBLC6-2SC6c
U704 | LQFP-64_10x10mm_P0.5mm | 1 | STM32G431RBTx | STM32G431RBT6
U705 | SOT-223-3_TabPin2 | 1 | AMS1117-3.3 | AMS1117-3.3
Heater |  | 4 | TBH25P10R0JE (https://www.digikey.ca/en/products/detail/ohmite/TBH25P10R0JE/824358) | TBH25P10R0JE (https://www.digikey.ca/en/products/detail/ohmite/TBH25P10R0JE/824358)
Mating pwr |  | 3
Mating signal |  | 1
C201, C307, C308, C309 | 0603 | 4 | 10uf | GRM188R6YA106MA73D
C202, C204, C207, C301, C305, C306, C310, C311, C312 | 0603 | 9 | 100nf | CL10B104KB8NNNC
C203, C206 | 0603 | 2 | 22uf | CL10A226MP8NUNE
C205, C302, C303, C304 | 0603 | 4 | 1uf | C0603C105K4RACTU
D201 | 0603 | 1 | RED | LTST-C191KRKT
D202 | D_SOD-323 | 1 | 1N5819WS | 1N5819WS
J201 | CONN_5040500891_MOL | 1 | 5040500891 | 5040500891
J203 | UJ20-C-H-G-SMT-1-P16-TR | 1 | USB_C_Receptacle_USB2.0_16P | UJ20-C-H-G-SMT-1-P16-TR
L301 | SRR1208 | 1 | SRR1208-120ML | SRR1208-120ML
P301, P302 | 436500200 2-pin | 2 | 436500200 | 436500200
Q302 | TO-126-3_Vertical | 1 | BD139 | BD139
R201, R203, R204, R205, R308 | 0603 | 5 | 10k | ERA-3AEB103V
R202, R302 | 0603 | 2 | 1.33k | ERA-3AEB1331V
R206, R207, R303, R311 | 0402 | 4 | 5.1k | RT0402BRD075K1L
R301 | 0805 | 1 | 100m | RCWE0805R100FKEA
R304, R305 | 0603 | 2 | 500 | ERA-3AEB4990V
R306 | 2512 | 1 | 5.1 | CRM2512-FX-5R10ELF
R307 | 0603 | 1 | 100k | ERA-3AEB104V
R309 | 0603 | 1 | 162k | CRCW0603162KFKEA
R310 | 0603 | 1 | 22.6k | ERA-3AEB2262V
SW201, SW202 | 430471035826 | 2 | SW_MEC_5E | 430471035826
U201 | SOT-223-3_TabPin2 | 1 | AMS1117-3.3 | AMS1117-3.3
U202 | ESP32-S3-WROOM-1 | 1 | ESP32-S3-WROOM-1-N8R8 | ESP32-S3-WROOM-1-N8R8
U203 | SOT-23-6 | 1 | USBLC6-2SC6 | USBLC6-2SC6
U301 | TSSOP-10_3x3mm_P0.5mm | 1 | DAC60501ZDGSR | DAC60501ZDGSR
U302 | SOT-23-6 | 1 | INA181A2IDBVR | INA181A2IDBVR
U303 | SOT-23-5 | 1 | TLV9061xDBV | LM358BAIDR
U304 | SOT-23-6 | 1 | LMR51420XFDDCR | LMR51420XFDDCR

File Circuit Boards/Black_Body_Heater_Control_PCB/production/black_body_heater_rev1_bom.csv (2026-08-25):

Designator | Footprint | Quantity | Value | LCSC Part #
C201 | 0603 | 1 | 10uf | GRM188R6YA106MA73D
C202, C204, C207, C301, C310, C311, C312 | 0603 | 7 | 100nf | CL10B104KB8NNNC
C203, C206 | 0603 | 2 | 22uf | CL10A226MP8NUNE
C302 | 0603 | 1 | 6.8uf | C1608X5R1E685K080AC
C303 | 0603 | 1 | 330pf | C0603C331J5GACTU
C304 | 1210 | 1 | 47uf | GRM32EC81C476KE15L
D201 | 0603 | 1 | RED | LTST-C191KRKT
D202 | D_SOD-323 | 1 | 1N5819WS | 1N5819WS
D301 | D_SMA | 1 | SMAJ24A | SMAJ24A
J201 | CONN_5040500891_MOL | 1 | 5040500891 | 5040500891
J203 | UJ20-C-H-G-SMT-1-P16-TR | 1 | USB_C_Receptacle_USB2.0_16P | UJ20-C-H-G-SMT-1-P16-TR
P301, P302 | 436500200 2-pin | 2 | 436500200 | 436500200
Q302 | TO-126-3_Vertical | 1 | BD139 | BD139
R201, R203, R205, R308, R309, R313 | 0603 | 6 | 10k | ERA-3AEB103V
R202, R302 | 0603 | 2 | 1.33k | ERA-3AEB1331V
R206, R207, R303, R311 | 0402 | 4 | 5.1k | RT0402BRD075K1L
R301 | 0805 | 1 | 100m | RCWE0805R100FKEA
R304, R305 | 0603 | 2 | 500 | ERA-3AEB4990V
R306 | 2512 | 1 | 5.1 | CRM2512-FX-5R10ELF
R307, R312 | 0603 | 2 | 100k | ERA-3AEB104V
R310 | 0603 | 1 | 1.37k | ERJ-3EKF1371V
SW201, SW202 | 430471035826 | 2 | SW_MEC_5E | SW_MEC_5E
U201 | SOT-223-3_TabPin2 | 1 | AMS1117-3.3 | AMS1117-3.3
U202 | ESP32-S3-WROOM-1 | 1 | ESP32-S3-WROOM-1-N8R8 | ESP32-S3-WROOM-1-N8R8
U203 | SOT-23-6 | 1 | USBLC6-2SC6 | USBLC6-2SC6
U301 | TSSOP-10_3x3mm_P0.5mm | 1 | DAC60501ZDGSR | DAC60501ZDGSR
U302 | SOT-23-6 | 1 | INA181A2IDBVR | INA181A2IDBVR
U303 | TPSM84209 | 1 | ~ | TPSM84209RKHR
U305 | SOIC-8_3.9x4.9mm_P1.27mm | 1 | LM358 | LM358BAIDR

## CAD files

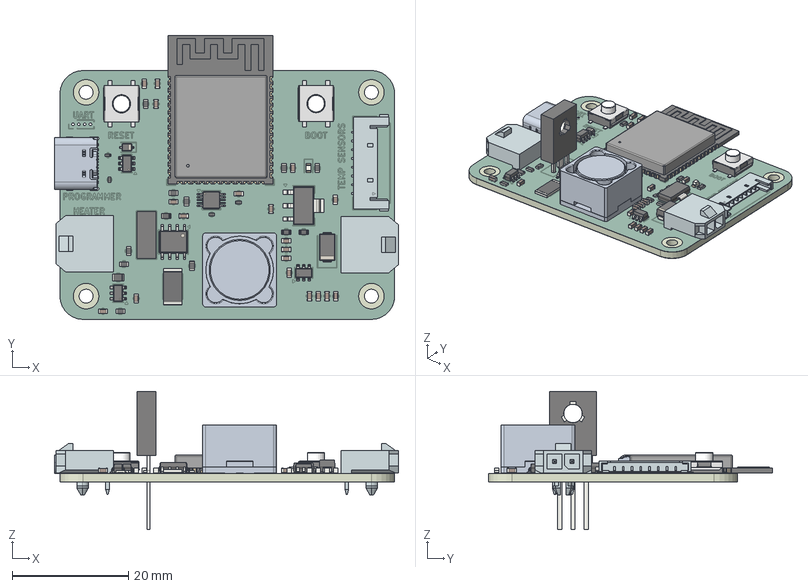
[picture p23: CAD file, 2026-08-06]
Circuit Boards/Black_Body_Heater_Control_PCB/.step
59.1 x 48.8 x 23.8 mm
R_0603_1608Metric x 12
C_0603_1608Metric x 19
R_0805_2012Metric
LED_0603_1608Metric
SOIC-8_3.9x4.9mm_P1.27mm
SOT-23-6 x 3
ESP32-S3-WROOM-1
TSSOP-10_3x3mm_P0.5mm
SRR1208
R_0402_1005Metric x 4
SOT-223
TO-126-3_Vertical
Same_Sky_UJ20-C-H-G-SMT-1-P16-TR
D_SOD-323
D_SMA
R_2512_6332Metric
base x 2
top cover x 2
Black_Body_Heater_Control_silkscreen x 2
Black_Body_Heater_Control_soldermask x 2
Black_Body_Heater_Control_PCB

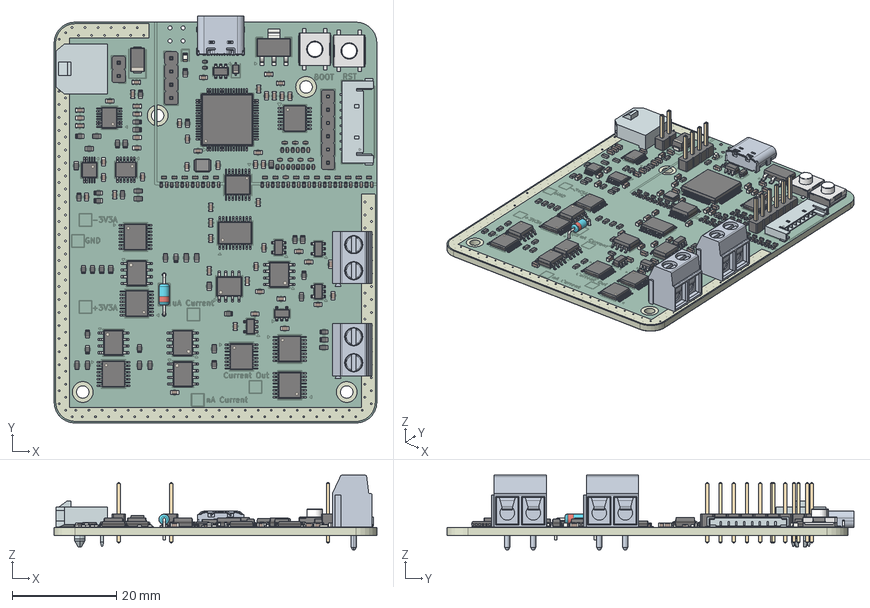
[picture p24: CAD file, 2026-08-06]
Circuit Boards/Black_Body_Temperature_Sensor_PCB/.step
62.0 x 78.2 x 14.4 mm
C_0603_1608Metric x 50
R_0603_1608Metric x 44
C_0402_1005Metric x 48
R_0402_1005Metric x 26
SOIC-8_3.9x4.9mm_P1.27mm x 6
MSOP-12-1EP_3x4.039mm_P0.65mm_EP1.651x2.845mm
D_DO-35_SOD27_P7.62mm_Horizontal
MSOP-16-1EP_3x4.039mm_P0.5mm_EP1.651x2.845mm
TSSOP-16_4.4x5mm_P0.65mm x 6
TSSOP-20_4.4x6.5mm_P0.65mm
SOT-223
TB002-500-02P_Blue - S x 2
TSSOP-14_4.4x5mm_P0.65mm
LED_0603_1608Metric
D_SMA
MSOP-10-1EP_3x3mm_P0.5mm_EP1.68x1.88mm
SOT-23-5 x 5
PinHeader_1x06_P254mm_Vertical
SSOP-16_3.9x4.9mm_P0.635mm
SOT-23-6
PinHeader_1x02_P254mm_Vertical
base x 2
top cover x 2
Same_Sky_UJ20-C-H-G-SMT-1-P16-TR
ABM8G
LQFP-64_10x10mm_P0.5mm
D_SOD-323
PinHeader_1x04_P254mm_Vertical
Black_Body_Temperature_Sensor_PCB_silkscreen x 2
Black_Body_Temperature_Sensor_PCB_soldermask x 2
Black_Body_Temperature_Sensor_PCB_PCB

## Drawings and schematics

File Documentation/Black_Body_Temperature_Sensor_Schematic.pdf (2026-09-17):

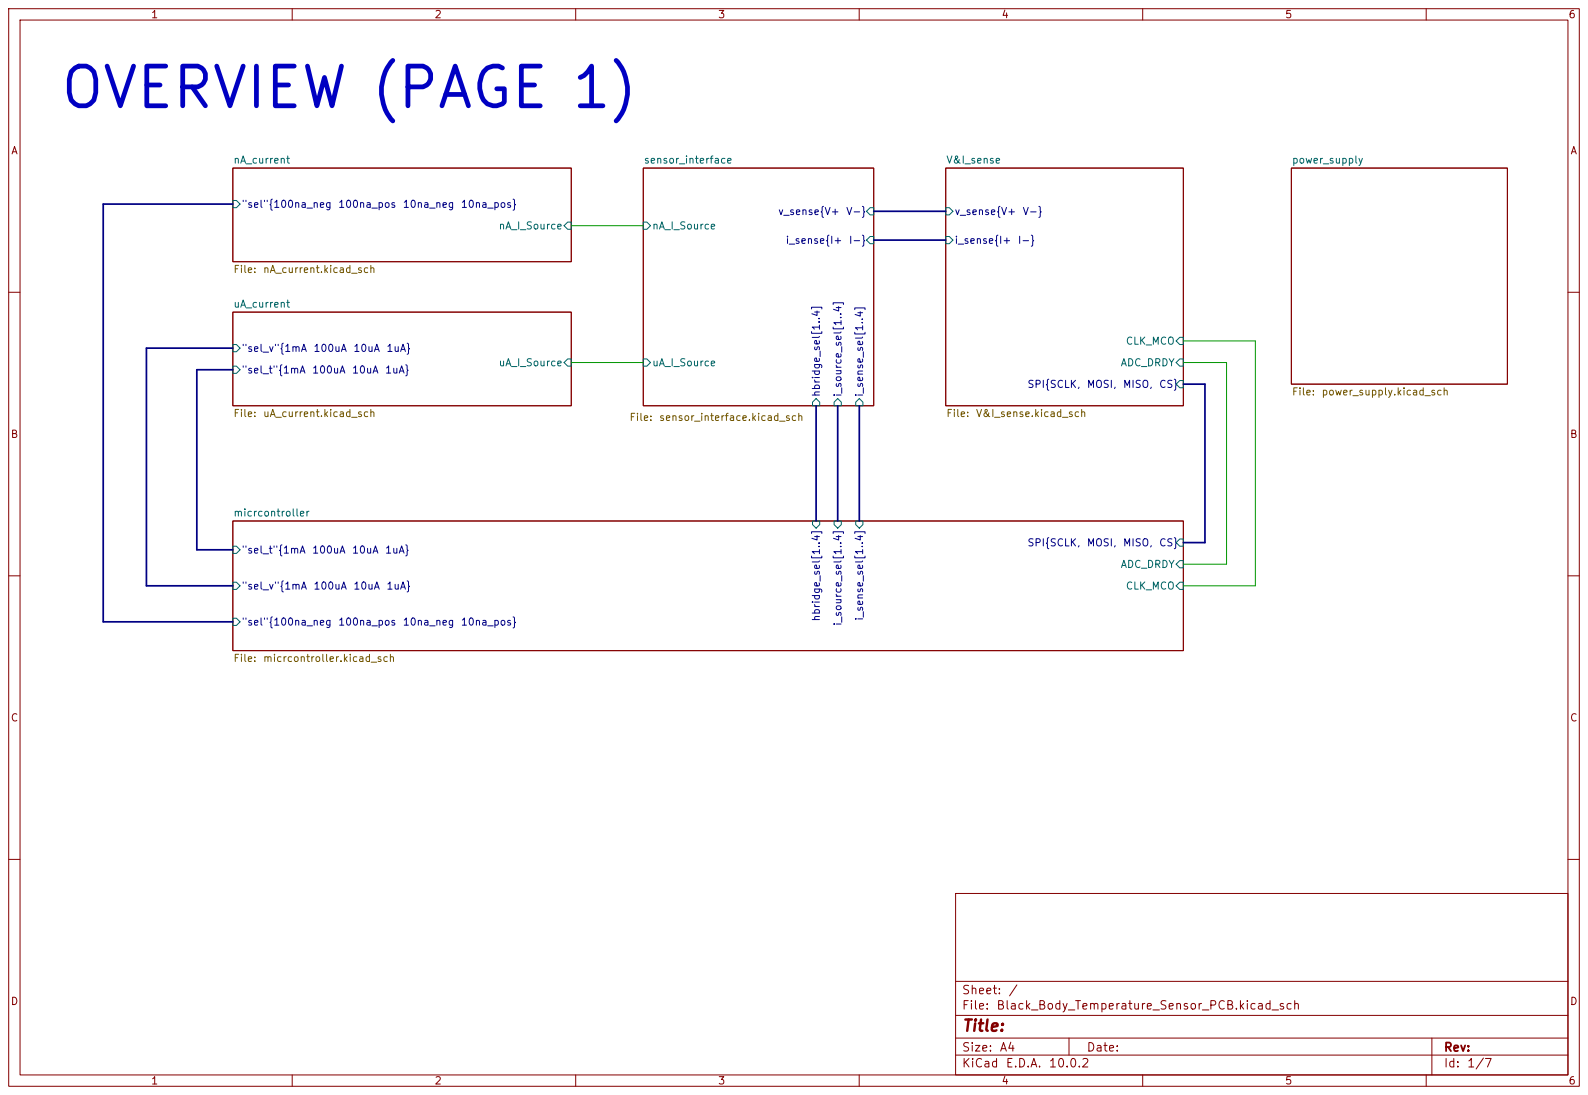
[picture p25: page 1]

SPI{SCLK, MOSI, MISO, CS} ADC_DRDY CLK_MCO

Size: A4 | Rev:
KiCad E.D.A. 10.0.2 | Id: 1/7

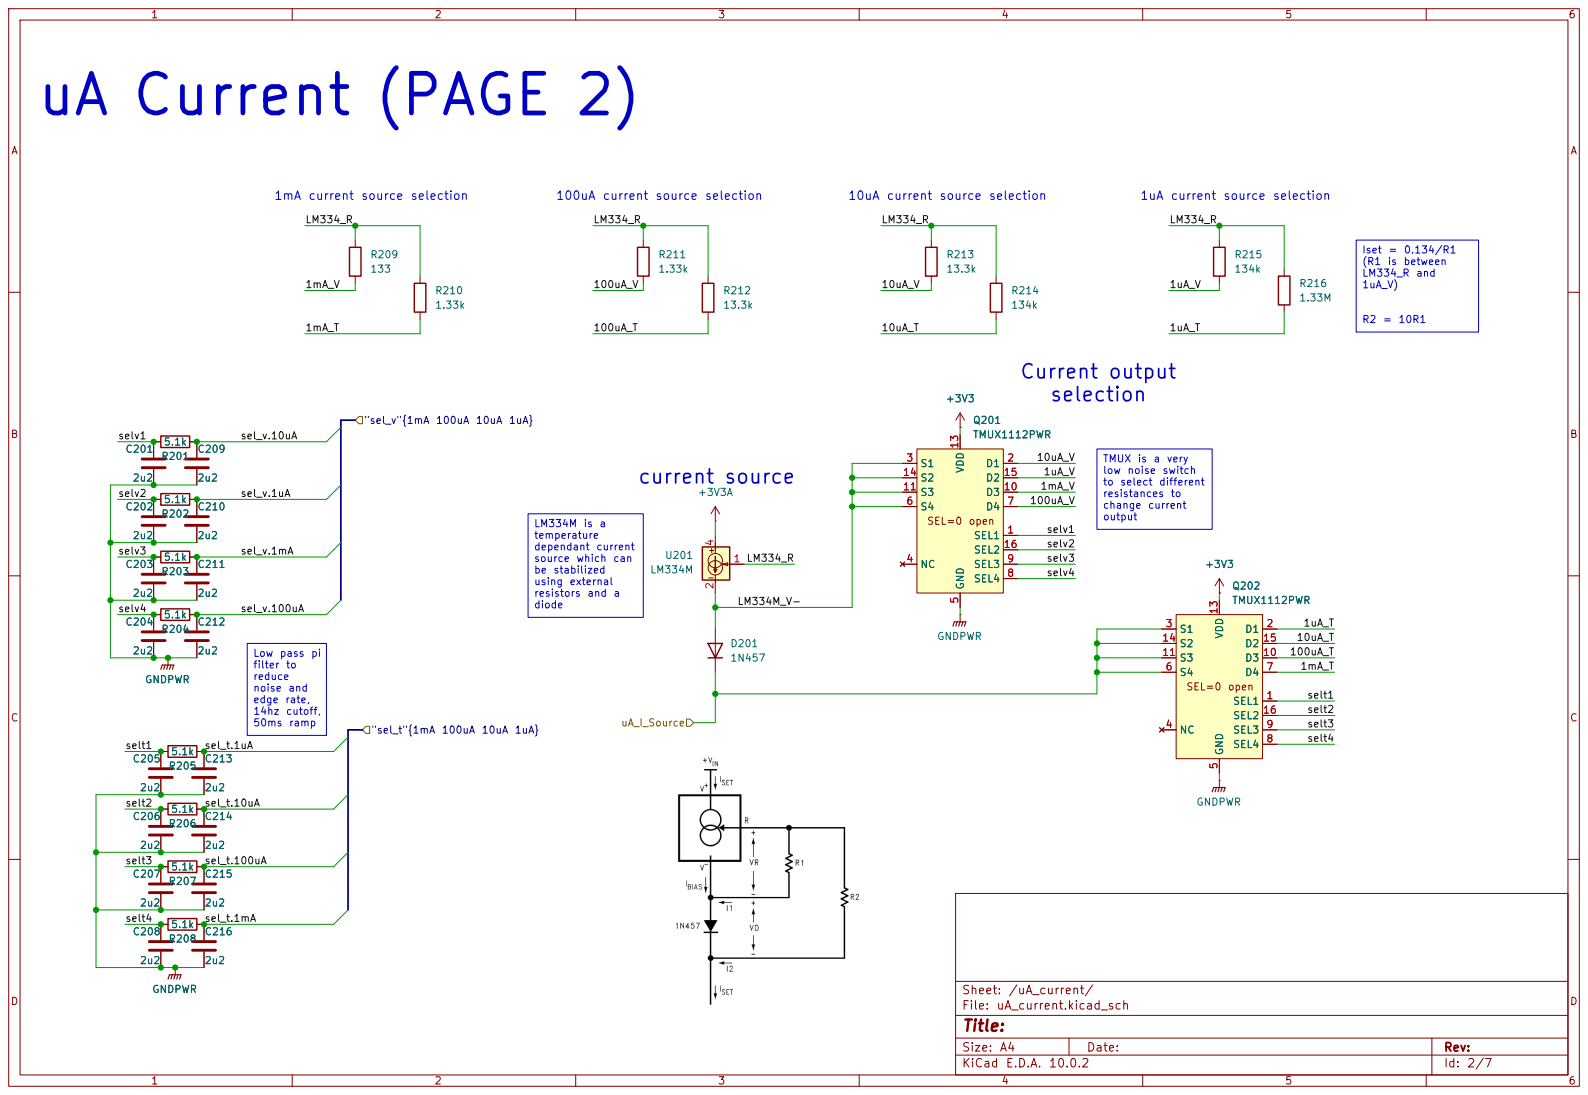
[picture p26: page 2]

TMUX is a very
low noise switch
to select different resistances to

sel_v.1uA
change current output Low pass pi filter to

temperature
dependant current source which can

be stabilized
using external resistors and a

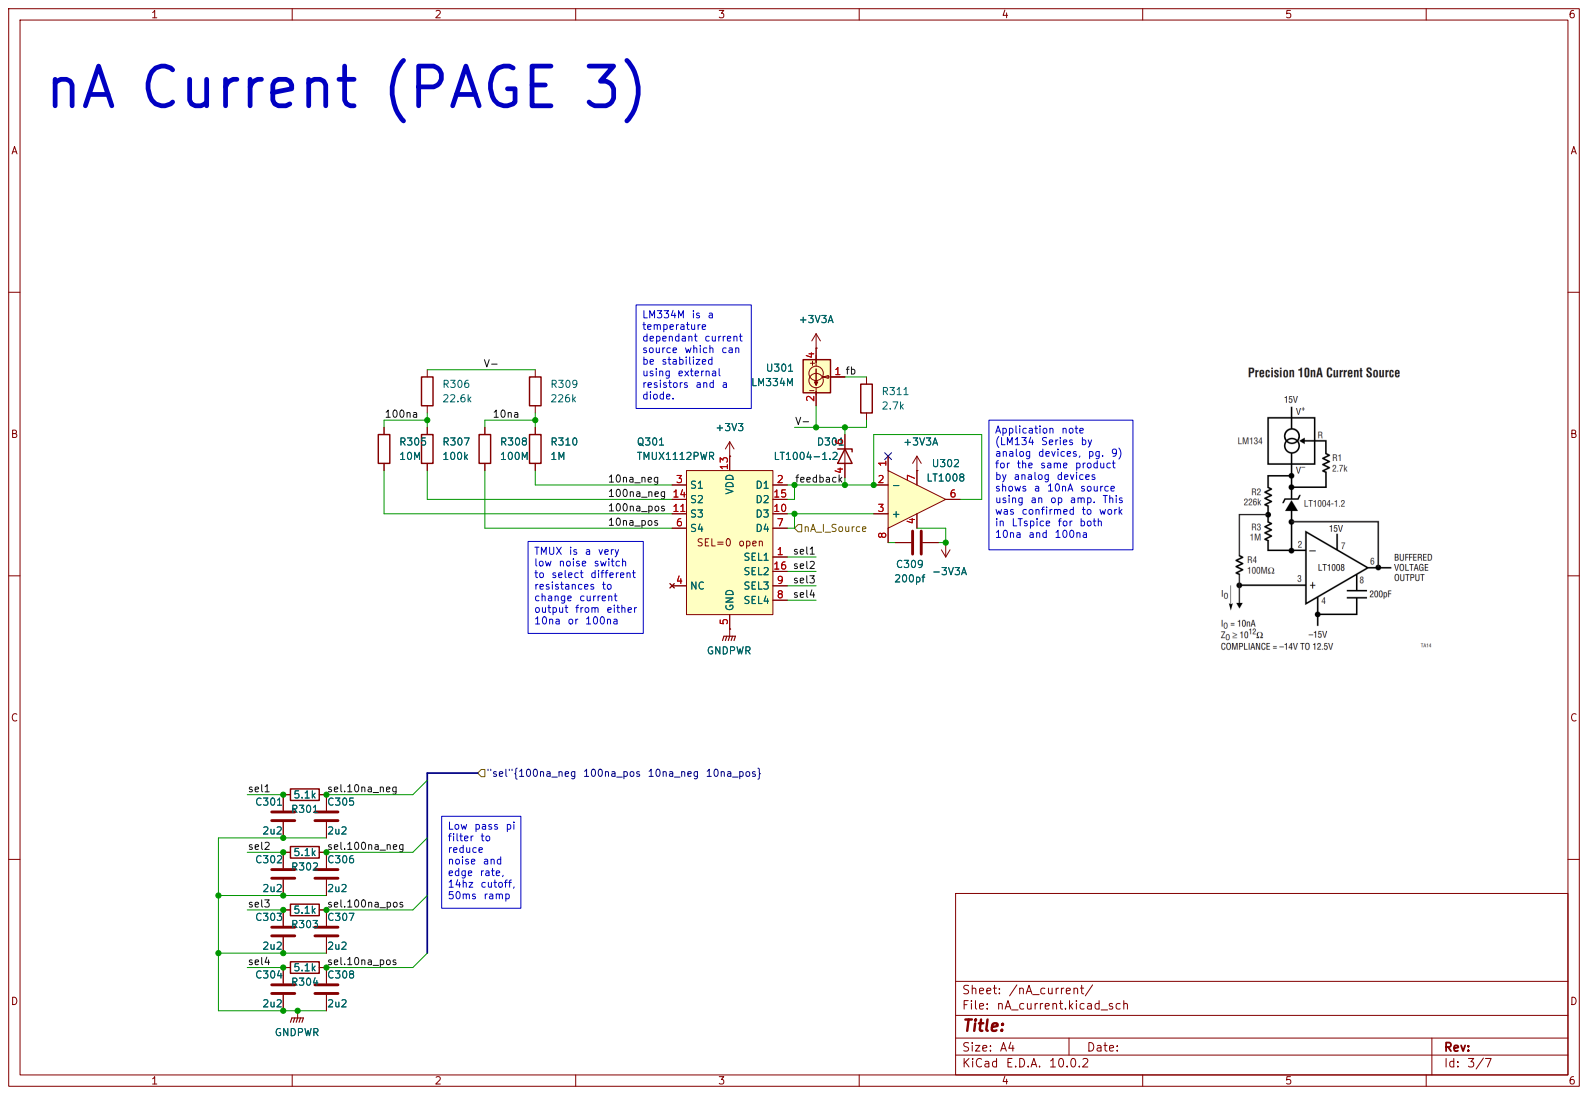
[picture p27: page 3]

in LTspice for both 10na and 100na nA Current (PAGE 3)

be stabilized
using external resistors and a

diode. Low pass pi filter to

Application note
(LM134 Series by
analog devices, pg. 9)
for the same product
by analog devices
shows a 10nA source using an op amp. This was confirmed to work

TMUX is a very
low noise switch
to select different resistances to

change current output from either 10na or 100na

edge rate, 14hz cutoff, 50ms ramp

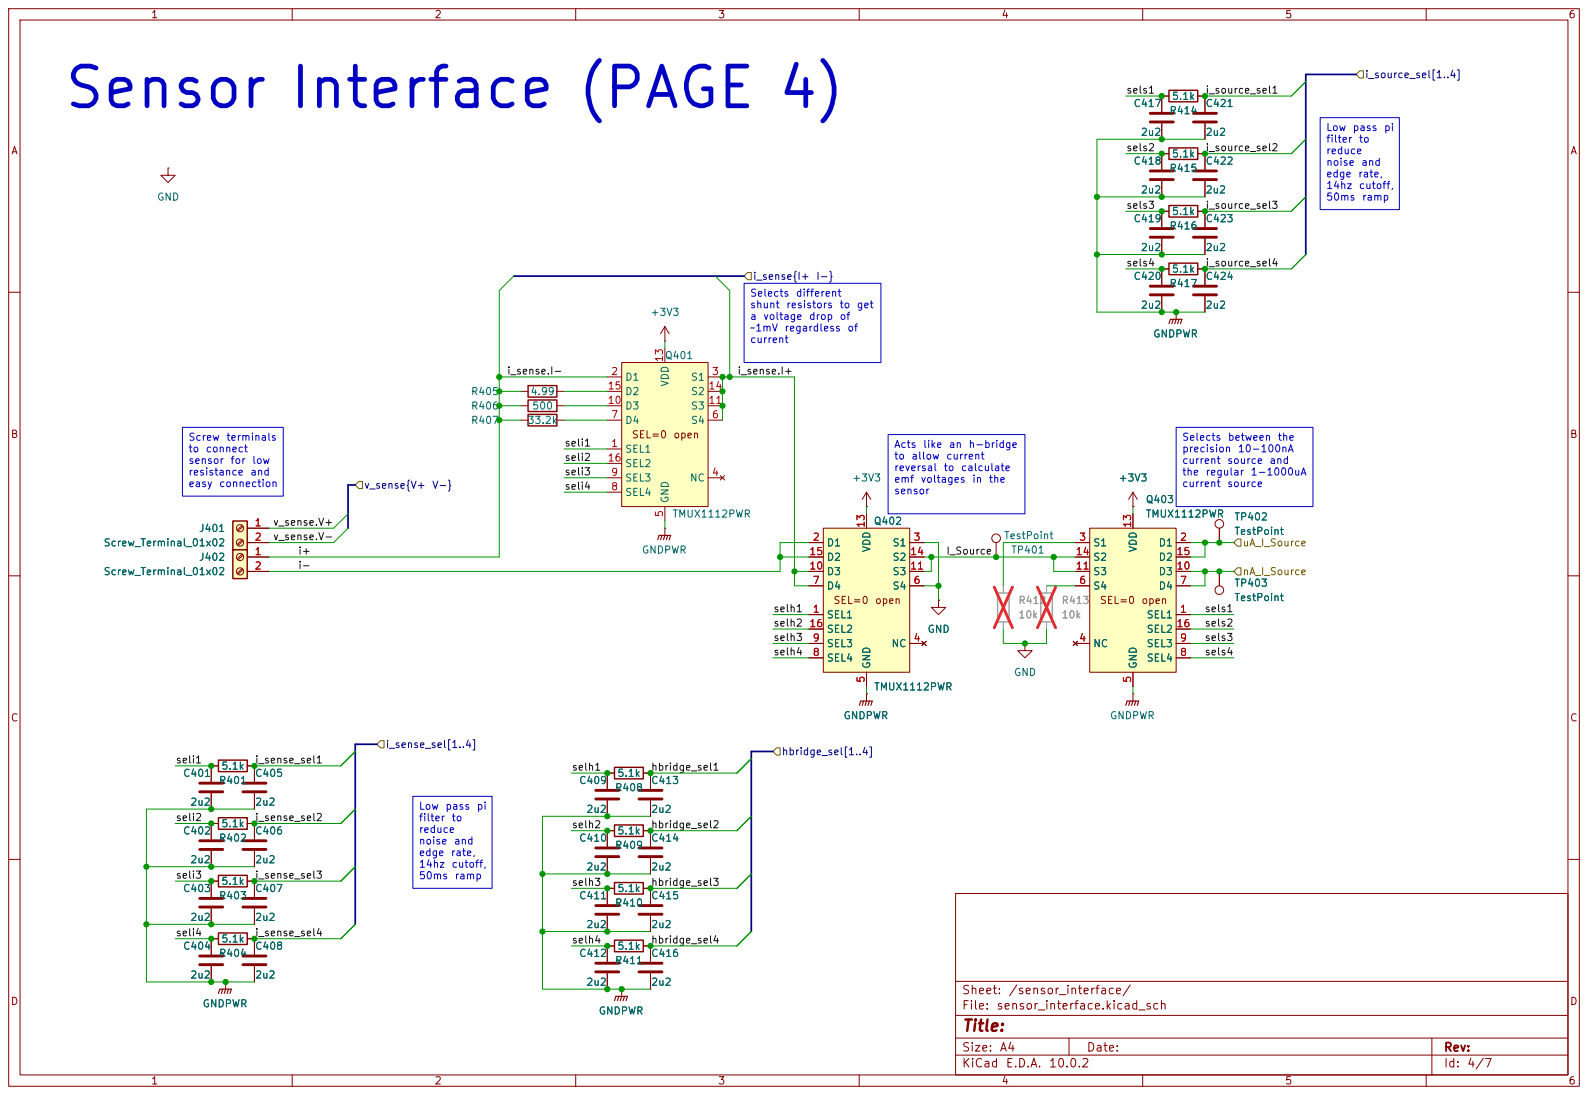
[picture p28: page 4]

Low pass pi filter to

sensor Selects different shunt resistors to get a voltage drop of ~1mV regardless of current Low pass pi filter to

Screw terminals
to connect sensor for low

Acts like an h-bridge
to allow current reversal to calculate

emf voltages in the

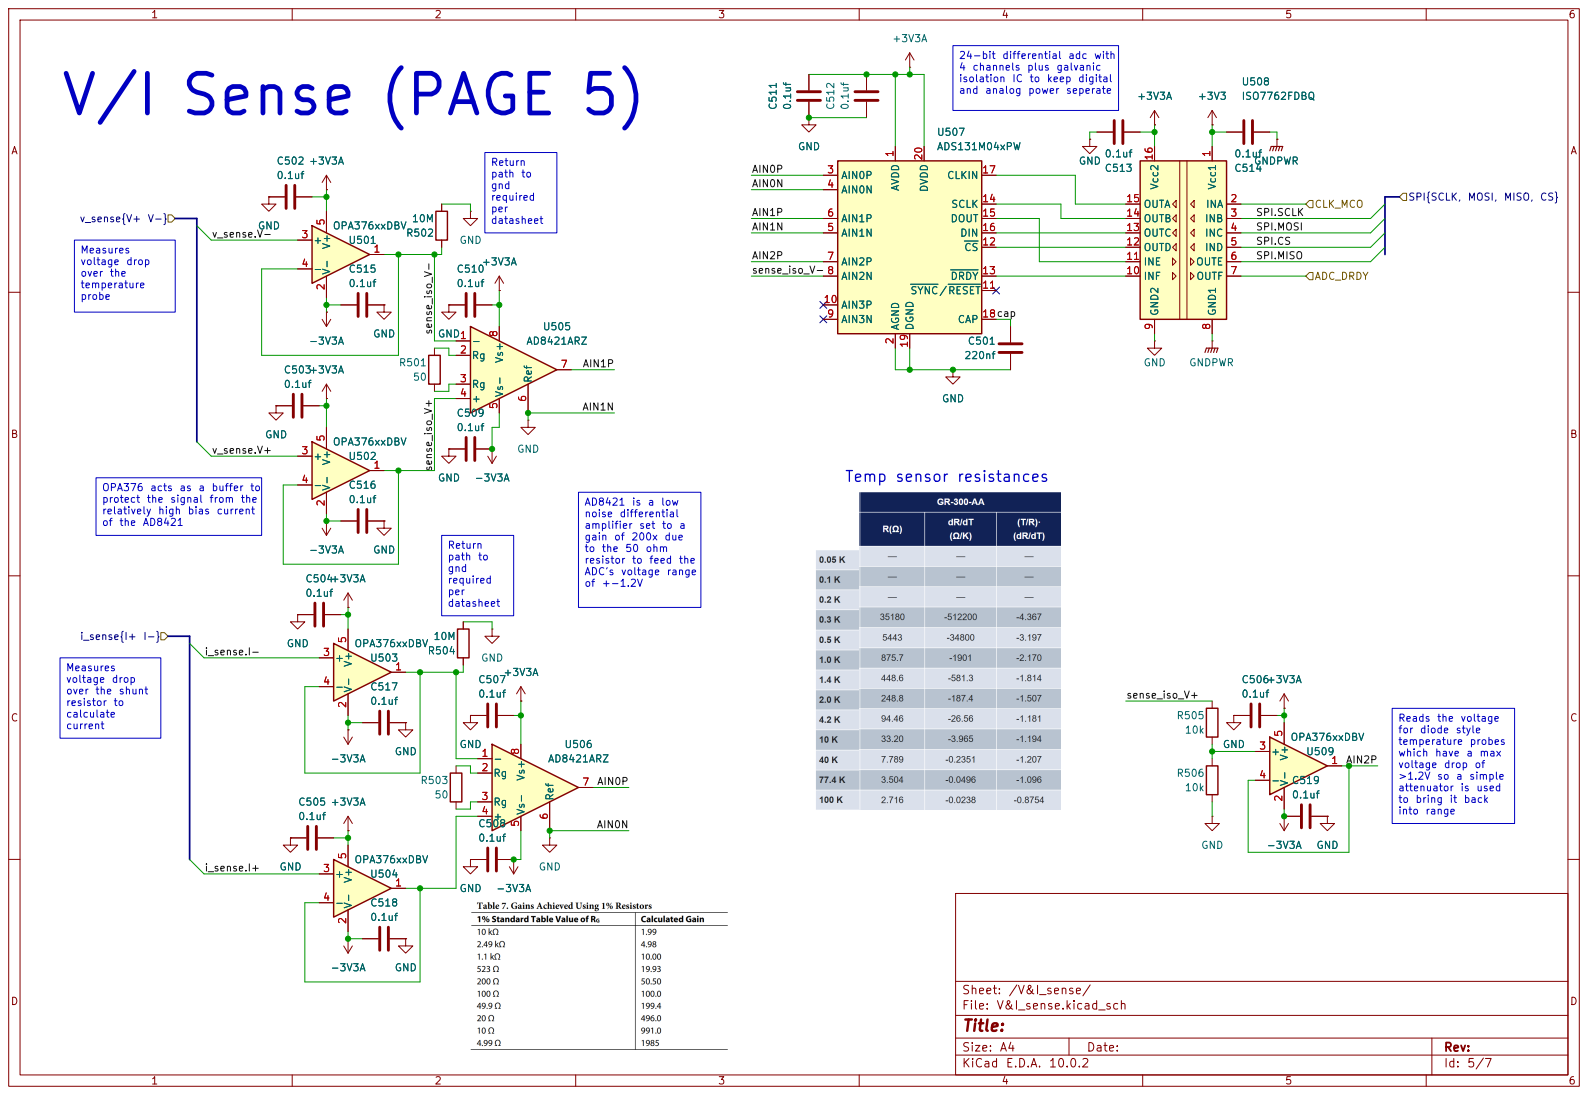
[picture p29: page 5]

24-bit differential adc with 4 channels plus galvanic
0.1ufGNDPWRV-

isolation IC to keep digital and analog power seperate V/I Sense (PAGE 5)

SPI.SCLK
SPI.MOSI SPI.CS

ADC's voltage range of +-1.2V OPA376 acts as a buffer to
protect the signal from the
relatively high bias current of the AD8421

noise differential amplifier set to a

gain of 200x due
to the 50 ohm
resistor to feed the

into range Measures
voltage drop
over the shunt resistor to

for diode style
temperature probes which have a max

voltage drop of >1.2V so a simple attenuator is used

to bring it back

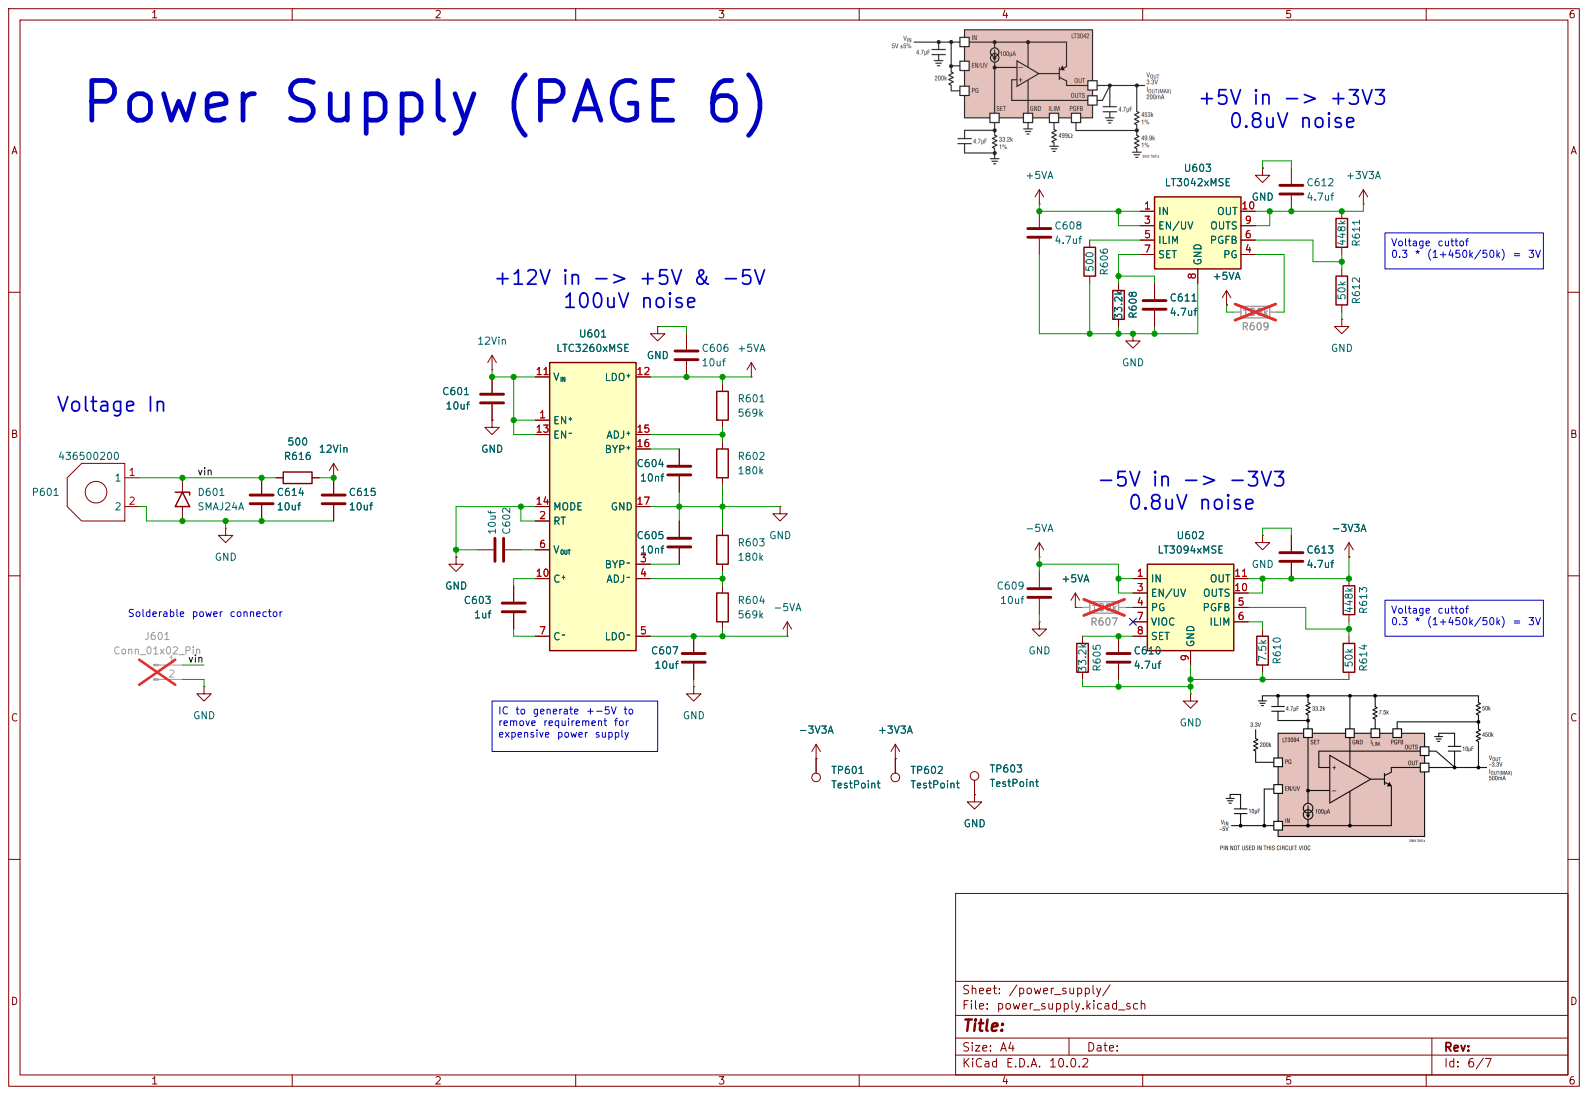
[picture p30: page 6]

Voltage cuttof 0.3 * (1+450k/50k) = 3V Voltage In

IC to generate +-5V to
remove requirement for expensive power supply

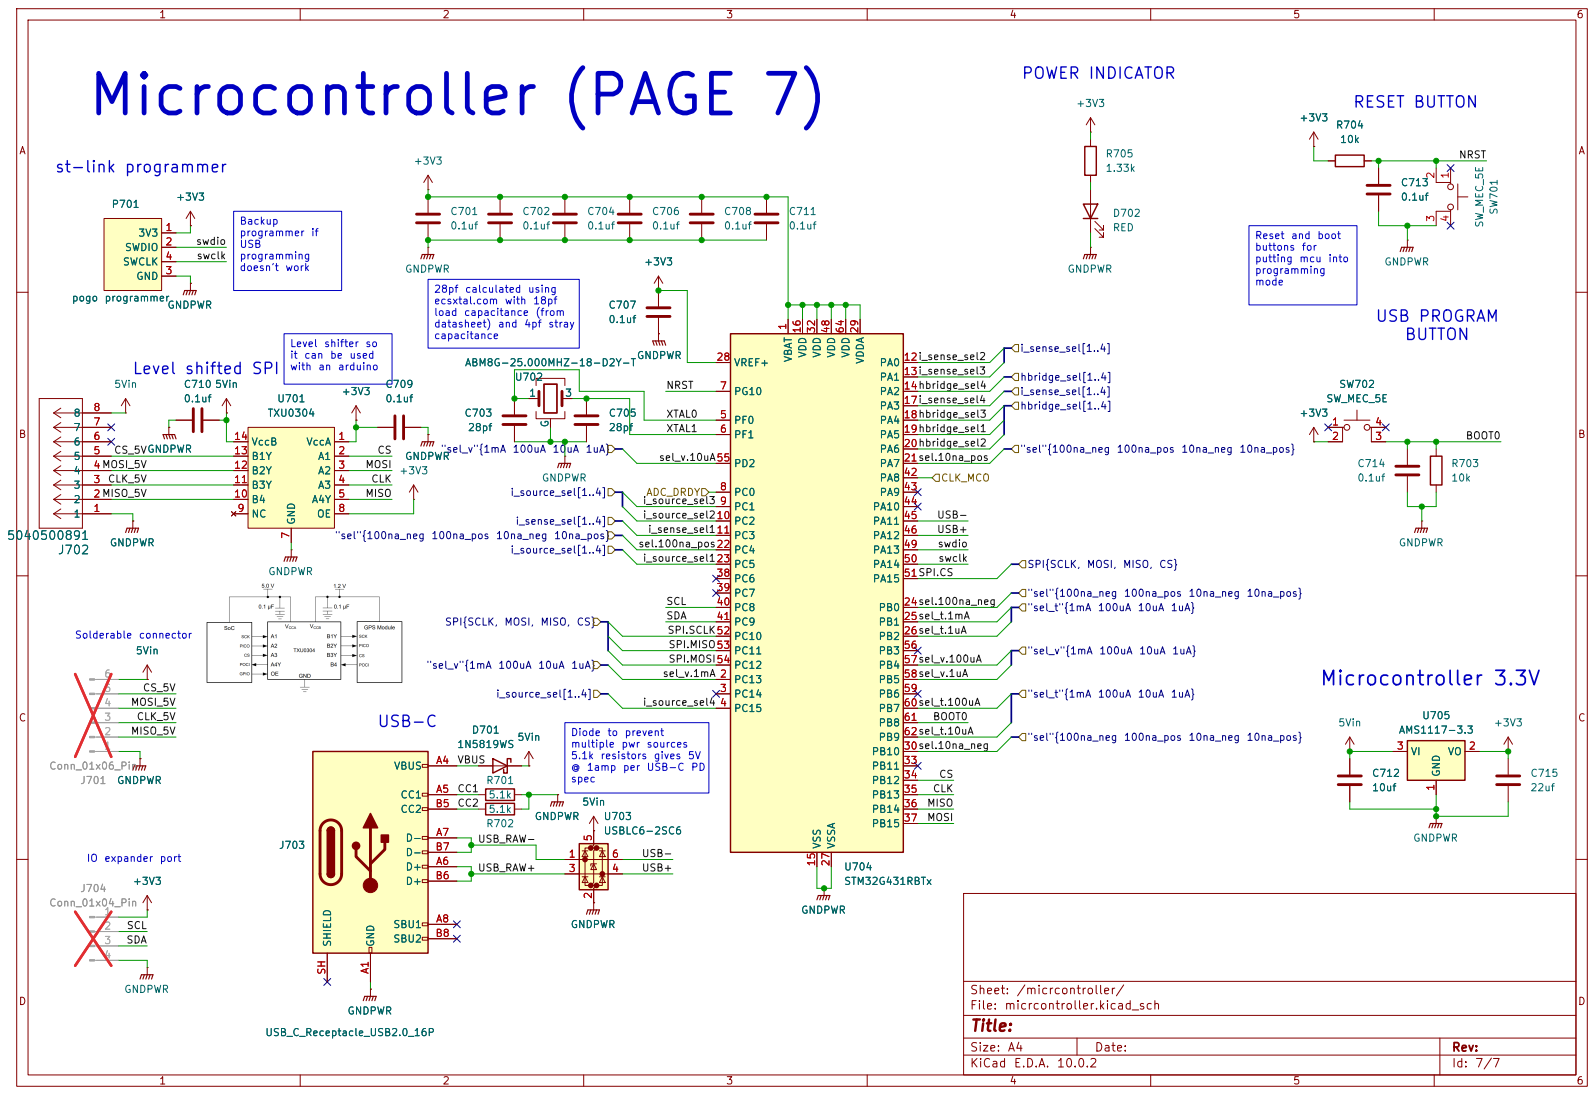
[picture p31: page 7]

capacitance Solderable connector st-link programmer

it can be used with an arduino Backup
programmer if USB

Reset and boot buttons for putting mcu into

programming mode 28pf calculated using

7 OE 8 NC 9 B4 10 B3Y 11 B2Y 12 B1Y 13 VccB 14 GNDPWR

SPI{SCLK, MOSI, MISO, CS}

SCL SPI.MISO
SDA SPI.MOSI SPI.SCLK
i_source_sel4 USB-

multiple pwr sources 5.1k resistors gives 5V @ 1amp per USB-C PD

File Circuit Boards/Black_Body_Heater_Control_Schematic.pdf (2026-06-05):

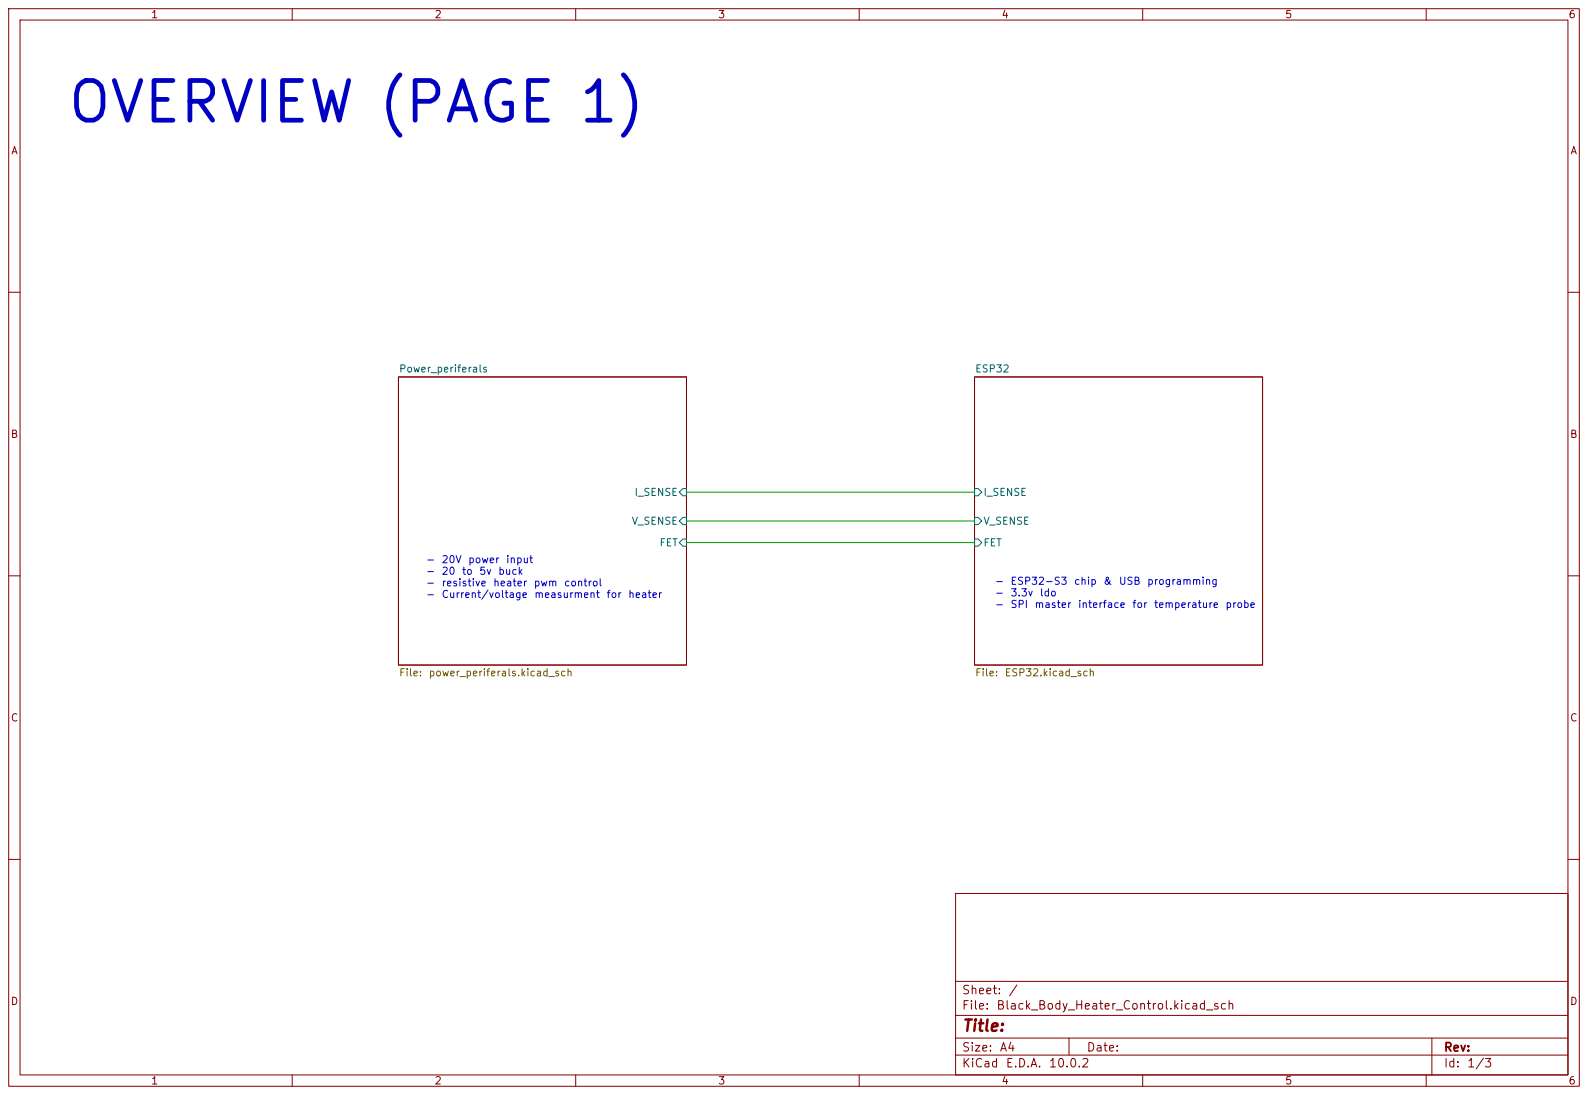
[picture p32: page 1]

Size: A4 | Rev:
KiCad E.D.A. 10.0.2 | Id: 1/3

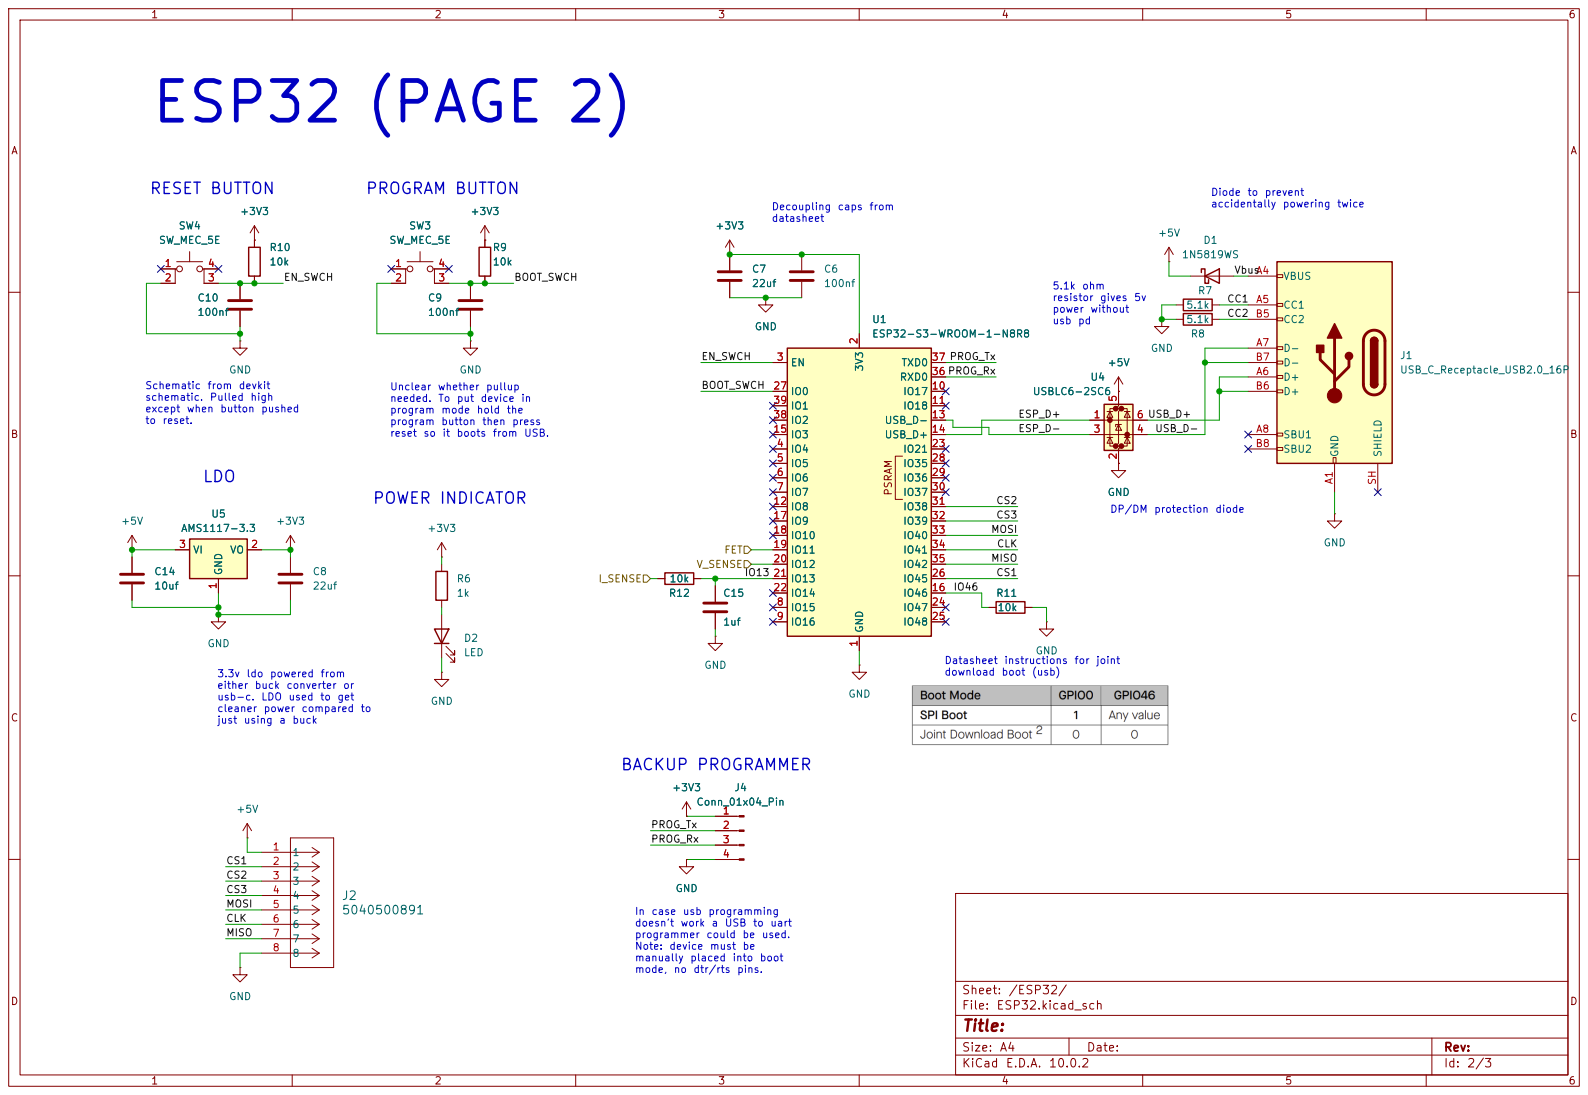
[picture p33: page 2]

resistor gives 5v power without usb pd 3.3v ldo powered from

5.1k | VBUS A4 CC1 A5 D+ A6 D- A7

reset so it boots from USB. Schematic from devkit schematic. Pulled high

Unclear whether pullup
needed. To put device in
program mode hold the program button then press

except when button pushed

either buck converter or usb-c. LDO used to get cleaner power compared to

In case usb programming
doesn't work a USB to uart programmer could be used. Note: device must be manually placed into boot mode, no dtr/rts pins.

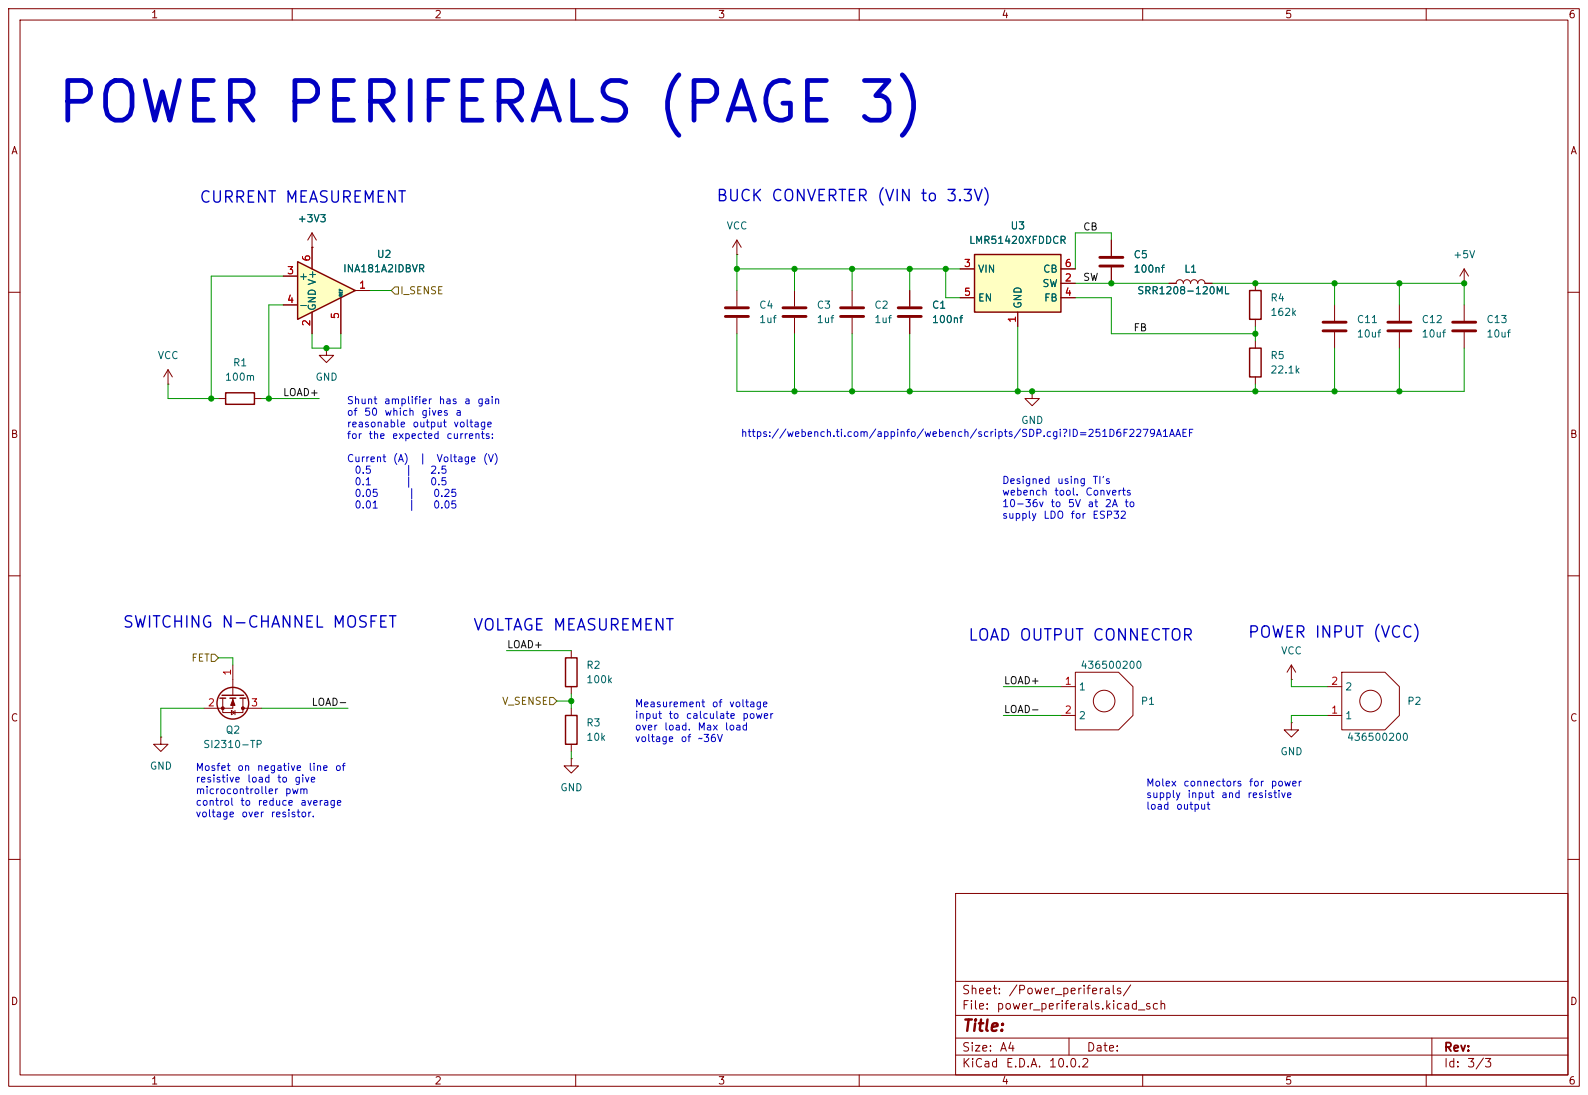
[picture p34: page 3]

BUCK CONVERTER (VIN to 3.3V)
1uf VCC

Shunt amplifier has a gain
of 50 which gives a
reasonable output voltage

https://webench.ti.com/appinfo/webench/scripts/SDP.cgi?ID=251D6F2279A1AAEF

Designed using TI's webench tool. Converts 10-36v to 5V at 2A to

input to calculate power over load. Max load

Mosfet on negative line of resistive load to give microcontroller pwm

control to reduce average

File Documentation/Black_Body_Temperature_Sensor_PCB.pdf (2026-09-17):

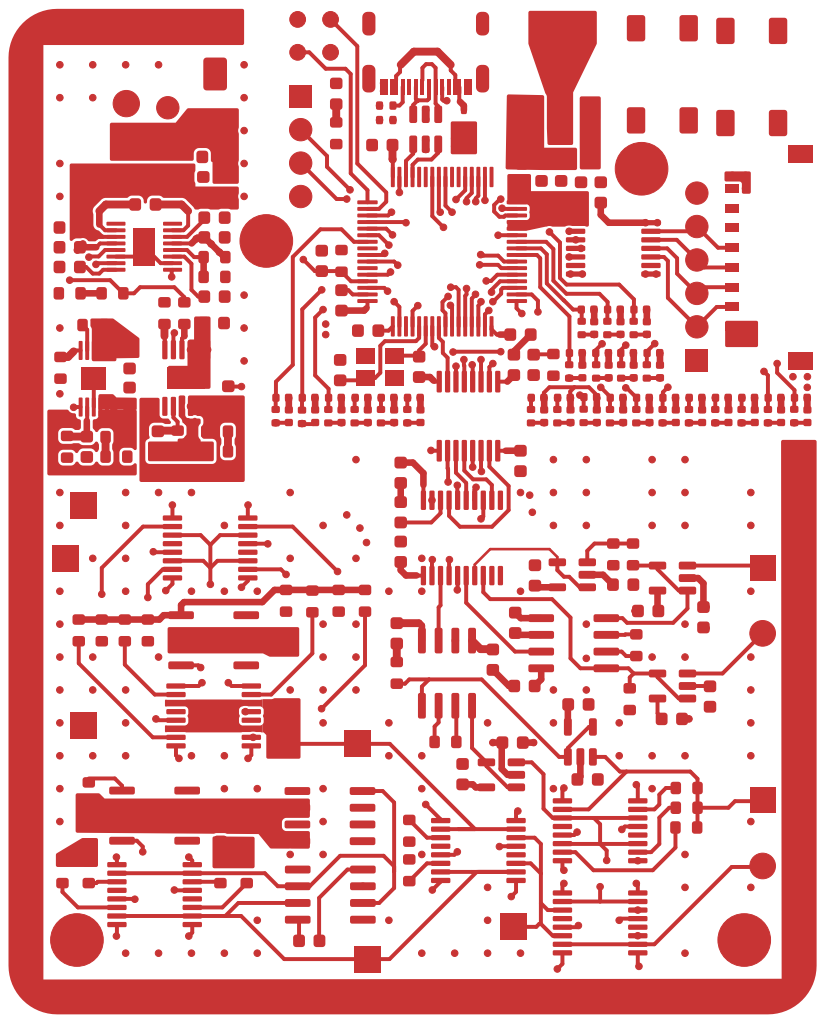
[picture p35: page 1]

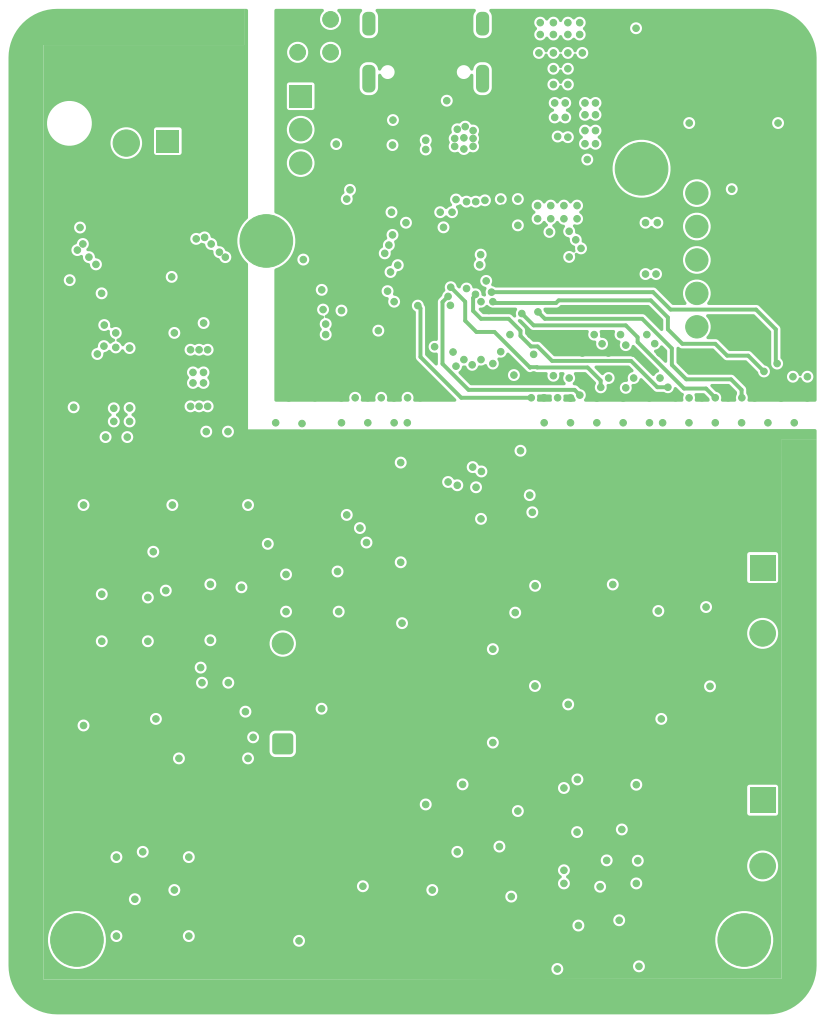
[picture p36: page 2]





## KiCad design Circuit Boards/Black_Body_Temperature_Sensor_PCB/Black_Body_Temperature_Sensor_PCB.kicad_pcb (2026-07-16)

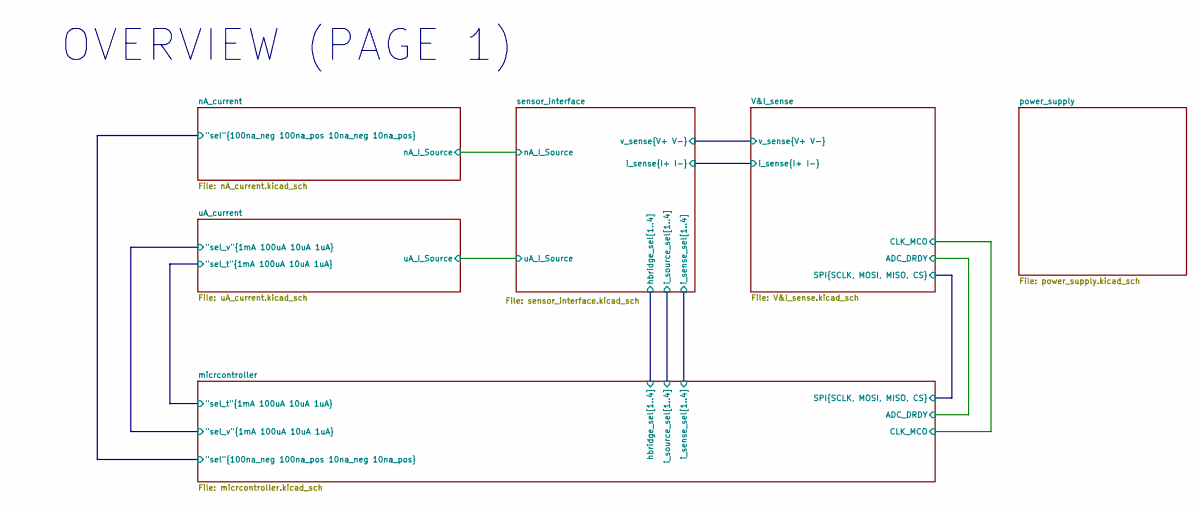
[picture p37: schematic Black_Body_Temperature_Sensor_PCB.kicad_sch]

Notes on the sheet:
OVERVIEW (PAGE 1)

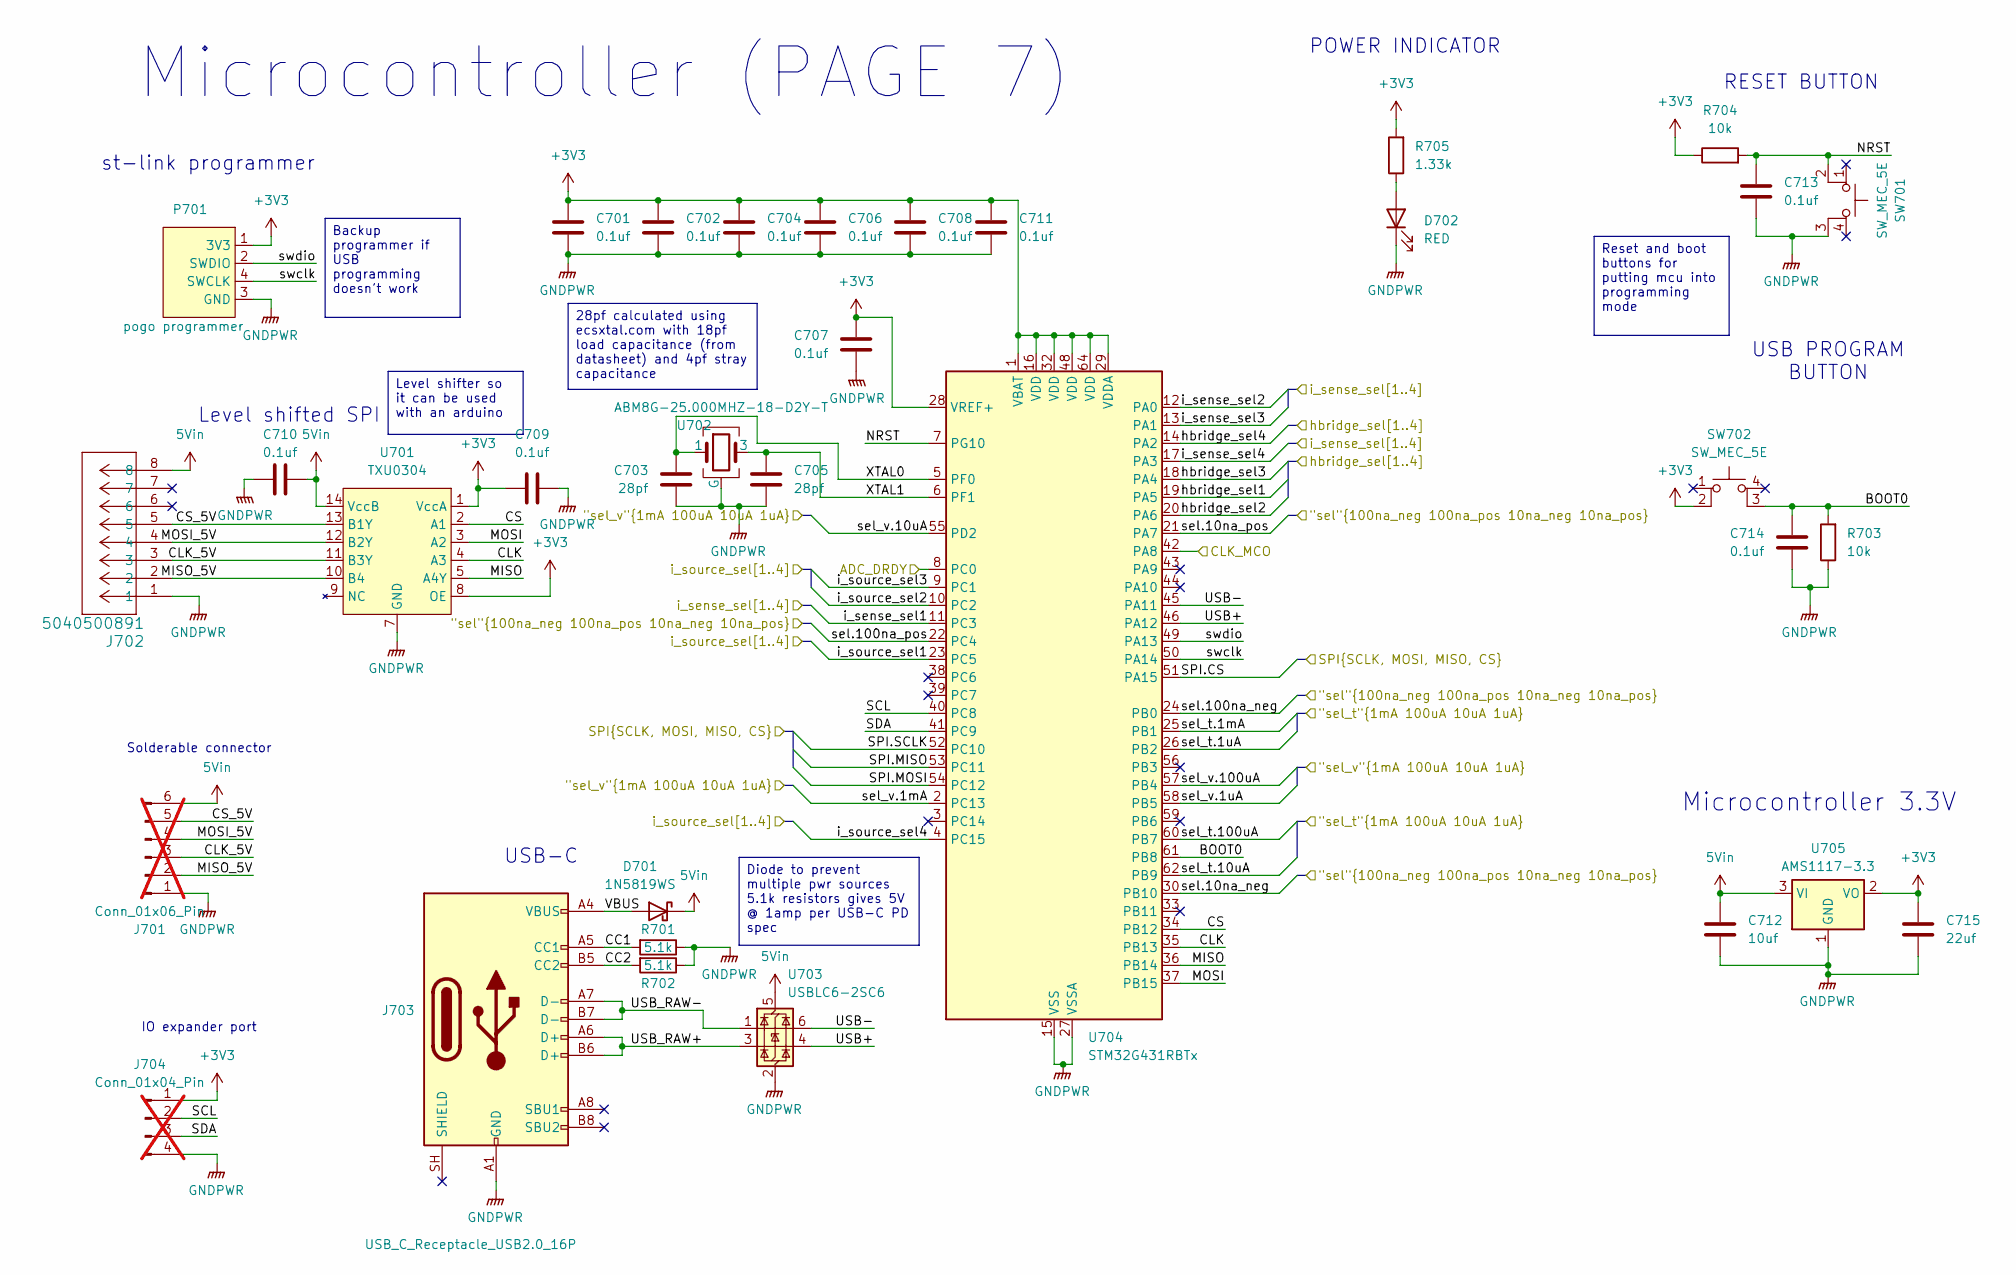
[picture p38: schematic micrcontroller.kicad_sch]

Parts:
C701, C702, C704, C706, C707, C708, C709, C710, C711, C713, C714: 0.1uf; C_0603_1608Metric; MPN CL10B104KB8NNNC
C703, C705: 28pf; C_0603_1608Metric; MPN CL10C270JB8NNNC
C712: 10uf; C_0603_1608Metric; MPN GRM188R6YA106MA73D
C715: 22uf; C_0603_1608Metric; MPN CL10A226MP8NUNE
D701: 1N5819WS; D_SOD-323; MPN 1N5819WS
D702: RED; LED_0603_1608Metric; MPN LTST-C191KRKT
J701: Conn_01x06_Pin; PinHeader_1x06_P2.54mm_Vertical; not fitted
J702: 5040500891; CONN_5040500891_MOL; MPN 5040500891
J703: USB_C_Receptacle_USB2.0_16P; UJ20-C-H-G-SMT-1-P16-TR; MPN UJ20-C-H-G-SMT-1-P16-TR
J704: Conn_01x04_Pin; PinHeader_1x04_P2.54mm_Vertical; not fitted
P701: pogo programmer; pogo_programmer
R701, R702: 5.1k; R_0402_1005Metric; MPN RT0402BRD075K1L
R703, R704: 10k; R_0603_1608Metric; MPN ERA-3AEB103V
R705: 1.33k; R_0603_1608Metric; MPN ERA-3AEB1331V
SW701, SW702: SW_MEC_5E; 430471035826; MPN 430471035826
U701: TXU0304; TSSOP-14_4.4x5mm_P0.65mm; MPN TXU0304PWR
U702: ABM8G-25.000MHZ-18-D2Y-T; MPN ABM8G-25.000MHZ-18-D2Y-T
U703: USBLC6-2SC6; SOT-23-6; MPN USBLC6-2SC6c
U704: STM32G431RBTx; LQFP-64_10x10mm_P0.5mm; MPN STM32G431RBT6
U705: AMS1117-3.3; SOT-223-3_TabPin2; MPN AMS1117-3.3

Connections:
5Vin: C710.1, C712.1, D701.1 (K), J701.6, J702.8, U701.14 (VccB), U703.5 (VBUS), U705.3 (VI)
+3V3: C701.1, C702.1, C704.1, C706.1, C707.1, C708.1, C709.1, C711.1, C715.1, J704.1, P701.1 (3V3), R704.1, R705.2, SW702.2, U701.1 (VccA), U701.8 (OE), U704.1 (VBAT), U704.16 (VDD), U704.28 (VREF+), U704.29 (VDDA), U704.32 (VDD), U704.48 (VDD), U704.64 (VDD), U705.2 (VO); also elsewhere on the board
/V&I_sense/ADC_DRDY: U704.8 (PC0); also elsewhere on the board
/V&I_sense/CLK_MCO: U704.42 (PA8); also elsewhere on the board
/V&I_sense/SPI.CS: U704.51 (PA15); also elsewhere on the board
/V&I_sense/SPI.MISO: U704.53 (PC11); also elsewhere on the board
/V&I_sense/SPI.MOSI: U704.54 (PC12); also elsewhere on the board
/V&I_sense/SPI.SCLK: U704.52 (PC10); also elsewhere on the board
/micrcontroller/BOOT0: C714.1, R703.2, SW702.3 (K), U704.61 (PB8)
/micrcontroller/CC1: J703.A5 (CC1), R701.2
/micrcontroller/CC2: J703.B5 (CC2), R702.2
/micrcontroller/CLK: U701.4 (A3), U704.35 (PB13)
/micrcontroller/CLK_5V: J701.3, J702.3, U701.11 (B3Y)
/micrcontroller/CS: U701.2 (A1), U704.34 (PB12)
/micrcontroller/CS_5V: J701.5, J702.5, U701.13 (B1Y)
/micrcontroller/MISO: U701.5 (A4Y), U704.36 (PB14)
/micrcontroller/MISO_5V: J701.2, J702.2, U701.10 (B4)
/micrcontroller/MOSI: U701.3 (A2), U704.37 (PB15)
/micrcontroller/MOSI_5V: J701.4, J702.4, U701.12 (B2Y)
/micrcontroller/NRST: C713.1, R704.2, SW701.2, U704.7 (PG10)
/micrcontroller/SCL: J704.2, U704.40 (PC8)
/micrcontroller/SDA: J704.3, U704.41 (PC9)
/micrcontroller/USB+: U703.4 (I/O2), U704.46 (PA12)
/micrcontroller/USB-: U703.6 (I/O1), U704.45 (PA11)
/micrcontroller/USB_RAW+: J703.A6 (D+), J703.B6 (D+), U703.3 (I/O2)
/micrcontroller/USB_RAW-: J703.A7 (D-), J703.B7 (D-), U703.1 (I/O1)
/micrcontroller/VBUS: D701.2 (A), J703.A4 (VBUS), J703.A9 (VBUS), J703.B4 (VBUS), J703.B9 (VBUS)
/micrcontroller/XTAL0: C703.1, U702.1, U704.5 (PF0)
/micrcontroller/XTAL1: C705.1, U702.3, U704.6 (PF1)
/micrcontroller/hbridge_sel1: U704.19 (PA5); also elsewhere on the board
/micrcontroller/hbridge_sel2: U704.20 (PA6); also elsewhere on the board
/micrcontroller/hbridge_sel3: U704.18 (PA4); also elsewhere on the board
/micrcontroller/hbridge_sel4: U704.14 (PA2); also elsewhere on the board
/micrcontroller/i_sense_sel1: U704.11 (PC3); also elsewhere on the board
/micrcontroller/i_sense_sel2: U704.12 (PA0); also elsewhere on the board
/micrcontroller/i_sense_sel3: U704.13 (PA1); also elsewhere on the board
/micrcontroller/i_sense_sel4: U704.17 (PA3); also elsewhere on the board
/micrcontroller/i_source_sel1: U704.23 (PC5); also elsewhere on the board
/micrcontroller/i_source_sel2: U704.10 (PC2); also elsewhere on the board
/micrcontroller/i_source_sel3: U704.9 (PC1); also elsewhere on the board
/micrcontroller/i_source_sel4: U704.4 (PC15); also elsewhere on the board
/micrcontroller/sel.10na_neg: U704.30 (PB10); also elsewhere on the board
/micrcontroller/sel.10na_pos: U704.21 (PA7); also elsewhere on the board
/micrcontroller/sel.100na_neg: U704.24 (PB0); also elsewhere on the board
/micrcontroller/sel.100na_pos: U704.22 (PC4); also elsewhere on the board
/micrcontroller/sel_t.1mA: U704.25 (PB1); also elsewhere on the board
/micrcontroller/sel_t.1uA: U704.26 (PB2); also elsewhere on the board
/micrcontroller/sel_t.10uA: U704.62 (PB9); also elsewhere on the board
/micrcontroller/sel_t.100uA: U704.60 (PB7); also elsewhere on the board
/micrcontroller/sel_v.1mA: U704.2 (PC13); also elsewhere on the board
/micrcontroller/sel_v.1uA: U704.58 (PB5); also elsewhere on the board
/micrcontroller/sel_v.10uA: U704.55 (PD2); also elsewhere on the board
/micrcontroller/sel_v.100uA: U704.57 (PB4); also elsewhere on the board
/micrcontroller/swclk: P701.4 (SWCLK), U704.50 (PA14)
/micrcontroller/swdio: P701.2 (SWDIO), U704.49 (PA13)
GNDPWR: C701.2, C702.2, C703.2, C704.2, C705.2, C706.2, C707.2, C708.2, C709.2, C710.2, C711.2, C712.2, C713.2, C714.2, C715.2, D702.1 (K), J701.1, J702.1, J703.A1 (GND), J703.A12 (GND), J703.B1 (GND), J703.B12 (GND), J704.4, P701.3 (GND), R701.1, R702.1, R703.1, SW701.3 (K), U701.7 (GND), U702.2 (G), U702.4 (G), U703.2 (GND), U704.15 (VSS), U704.27 (VSSA), U704.31 (VSS), U704.47 (VSS), U704.63 (VSS), U705.1 (GND); also elsewhere on the board
unnamed: D702.2 (A), R705.1

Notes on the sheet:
USB-C
Microcontroller (PAGE 7)
Level shifted SPI
POWER INDICATOR
IO expander port
USB PROGRAM BUTTON
RESET BUTTON
Microcontroller 3.3V
Solderable connector
st-link programmer
Level shifter so it can be used with an arduino
Reset and boot buttons for putting mcu into programming mode
Diode to prevent multiple pwr sources 5.1k resistors gives 5V @ 1amp per USB-C PD spec
28pf calculated using ecsxtal.com with 18pf load capacitance (from datasheet) and 4pf stray capacitance
Backup programmer if USB programming doesn't work

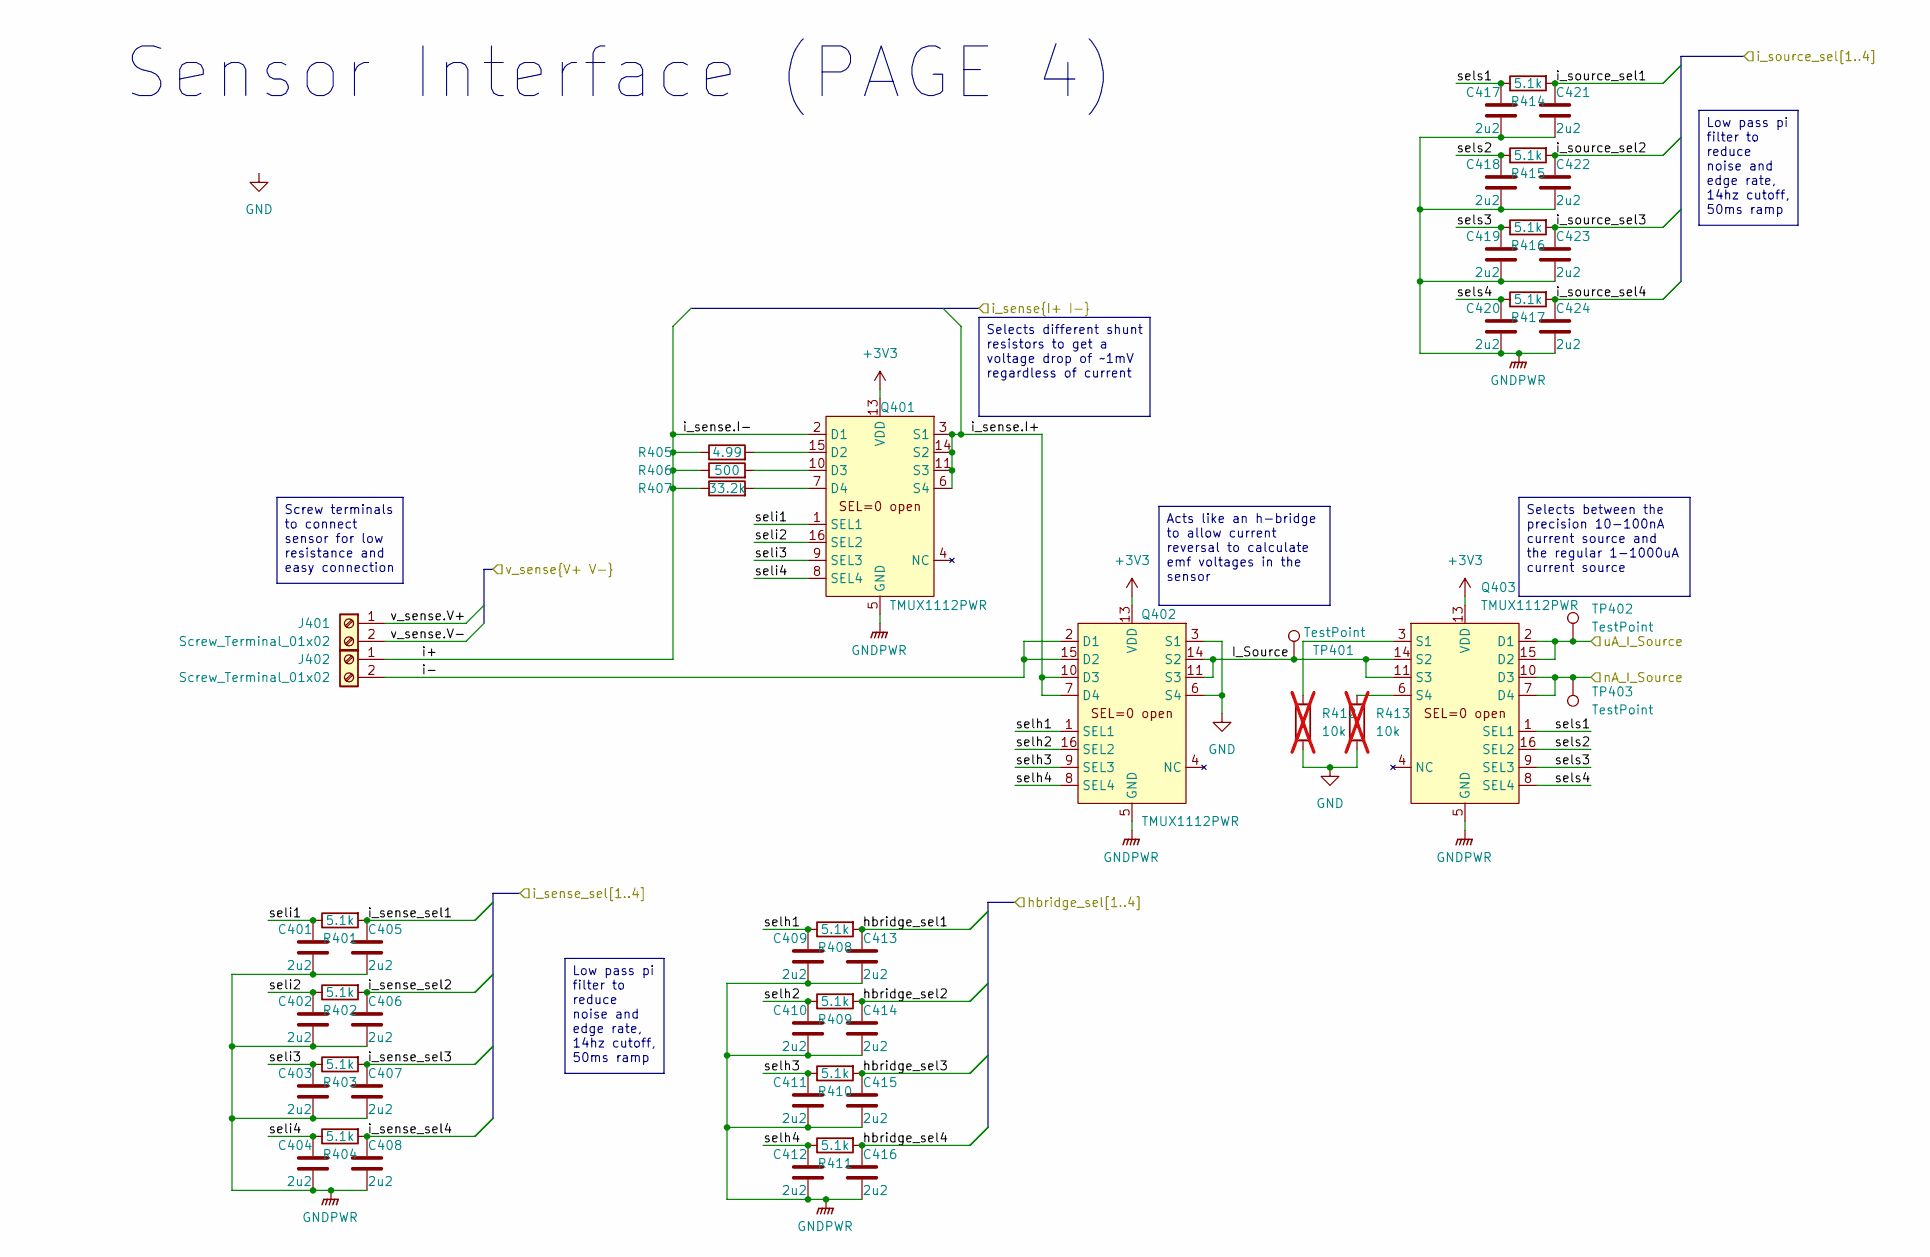
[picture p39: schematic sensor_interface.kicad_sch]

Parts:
C401, C402, C403, C404, C405, C406, C407, C408, C409, C410, C411, C412, C413, C414, C415, C416, C417, C418, C419, C420, C421, C422, C423, C424: 2u2; C_0402_1005Metric; MPN GRM155R61E225ME15D
J401, J402: Screw_Terminal_01x02; CUI_TB002-500-02BE; MPN TB002-500-02BE
Q401, Q402, Q403: TMUX1112PWR; TSSOP-16_4.4x5mm_P0.65mm; MPN TMUX1112PWR
R401, R402, R403, R404, R408, R409, R410, R411, R414, R415, R416, R417: 5.1k; R_0402_1005Metric; MPN RT0402BRD075K1L
R405: 4.99; R_0603_1608Metric; MPN RN73C1J4R99BTD
R406: 500; R_0603_1608Metric; MPN ERA-3AEB4990V
R407: 33.2k; R_0603_1608Metric; MPN ERA-3AEB3322V
R412, R413: 10k; R_0603_1608Metric; MPN ERA-3AEB103V; not fitted
TP401, TP402, TP403: TestPoint; TestPoint_Pad_2.0x2.0mm

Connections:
+3V3: Q401.13 (VDD), Q402.13 (VDD), Q403.13 (VDD); also elsewhere on the board
/V&I_sense/i_sense.I+: Q401.3 (S1), Q401.6 (S4), Q401.11 (S3), Q401.14 (S2), Q402.7 (D4), Q402.10 (D3); also elsewhere on the board
/V&I_sense/i_sense.I-: J402.1, Q401.2 (D1), R405.1, R406.1, R407.1; also elsewhere on the board
/V&I_sense/v_sense.V+: J401.1; also elsewhere on the board
/V&I_sense/v_sense.V-: J401.2; also elsewhere on the board
/micrcontroller/hbridge_sel1: C413.1, R408.2; also elsewhere on the board
/micrcontroller/hbridge_sel2: C414.1, R409.2; also elsewhere on the board
/micrcontroller/hbridge_sel3: C415.1, R410.2; also elsewhere on the board
/micrcontroller/hbridge_sel4: C416.1, R411.2; also elsewhere on the board
/micrcontroller/i_sense_sel1: C405.1, R401.2; also elsewhere on the board
/micrcontroller/i_sense_sel2: C406.1, R402.2; also elsewhere on the board
/micrcontroller/i_sense_sel3: C407.1, R403.2; also elsewhere on the board
/micrcontroller/i_sense_sel4: C408.1, R404.2; also elsewhere on the board
/micrcontroller/i_source_sel1: C421.1, R414.2; also elsewhere on the board
/micrcontroller/i_source_sel2: C422.1, R415.2; also elsewhere on the board
/micrcontroller/i_source_sel3: C423.1, R416.2; also elsewhere on the board
/micrcontroller/i_source_sel4: C424.1, R417.2; also elsewhere on the board
/nA_current/nA_I_Source: Q403.7 (D4), Q403.10 (D3), TP403.1 (1_1); also elsewhere on the board
/sensor_interface/I_Source: Q402.11 (S3), Q402.14 (S2), Q403.11 (S3), Q403.14 (S2), TP401.1 (1_1)
/sensor_interface/i-: J402.2, Q402.2 (D1), Q402.15 (D2)
/sensor_interface/selh1: C409.1, Q402.1 (SEL1), R408.1
/sensor_interface/selh2: C410.1, Q402.16 (SEL2), R409.1
/sensor_interface/selh3: C411.1, Q402.9 (SEL3), R410.1
/sensor_interface/selh4: C412.1, Q402.8 (SEL4), R411.1
/sensor_interface/seli1: C401.1, Q401.1 (SEL1), R401.1
/sensor_interface/seli2: C402.1, Q401.16 (SEL2), R402.1
/sensor_interface/seli3: C403.1, Q401.9 (SEL3), R403.1
/sensor_interface/seli4: C404.1, Q401.8 (SEL4), R404.1
/sensor_interface/sels1: C417.1, Q403.1 (SEL1), R414.1
/sensor_interface/sels2: C418.1, Q403.16 (SEL2), R415.1
/sensor_interface/sels3: C419.1, Q403.9 (SEL3), R416.1
/sensor_interface/sels4: C420.1, Q403.8 (SEL4), R417.1
/sensor_interface/uA_I_Source: Q403.2 (D1), Q403.15 (D2), TP402.1 (1_1); also elsewhere on the board
GND: Q402.3 (S1), Q402.6 (S4), R412.2, R413.2; also elsewhere on the board
GNDPWR: C401.2, C402.2, C403.2, C404.2, C405.2, C406.2, C407.2, C408.2, C409.2, C410.2, C411.2, C412.2, C413.2, C414.2, C415.2, C416.2, C417.2, C418.2, C419.2, C420.2, C421.2, C422.2, C423.2, C424.2, Q401.5 (GND), Q402.5 (GND), Q403.5 (GND); also elsewhere on the board
unnamed: Q401.15 (D2), R405.2
unnamed: Q401.10 (D3), R406.2
unnamed: Q401.7 (D4), R407.2
unnamed: Q403.3 (S1), R412.1
unnamed: Q403.6 (S4), R413.1

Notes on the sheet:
Sensor Interface (PAGE 4)
Low pass pi filter to reduce noise and edge rate, 14hz cutoff, 50ms ramp
Acts like an h-bridge to allow current reversal to calculate emf voltages in the sensor
Selects different shunt resistors to get a voltage drop of ~1mV regardless of current
Screw terminals to connect sensor for low resistance and easy connection
Selects between the precision 10-100nA current source and the regular 1-1000uA current source

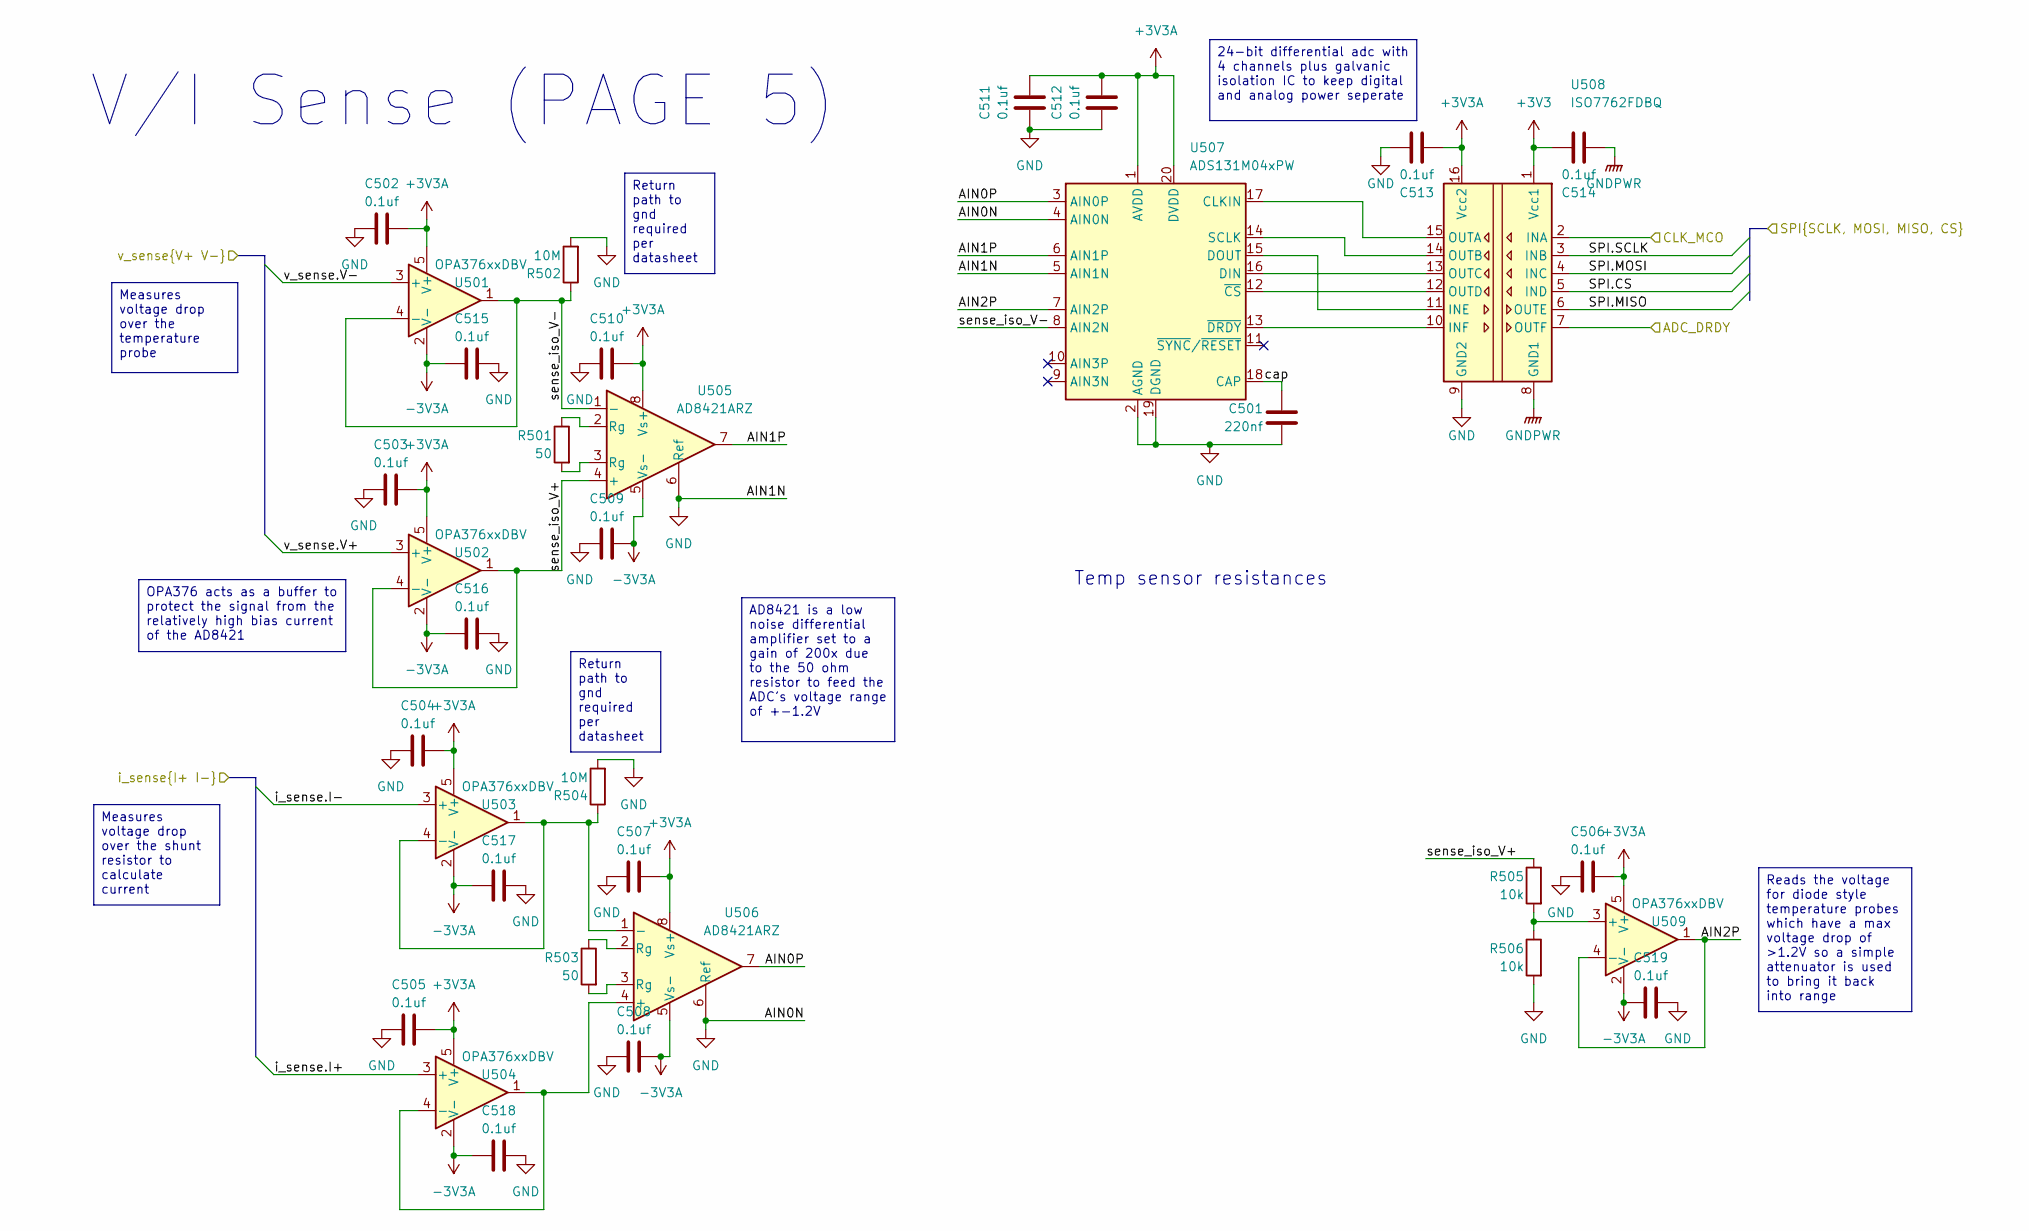
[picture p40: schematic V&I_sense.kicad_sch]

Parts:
C501: 220nf; C_0603_1608Metric; MPN GCM188R71H224KA64D
C502, C503, C504, C505, C506, C507, C508, C509, C510, C511, C512, C513, C514, C515, C516, C517, C518, C519: 0.1uf; C_0603_1608Metric; MPN CL10B104KB8NNNC
R501, R503: 50; R_0603_1608Metric; MPN ERA-3AEB49R9V
R502, R504: 10M; R_0603_1608Metric; MPN CRCW060310M0DHEAP
R505, R506: 10k; R_0603_1608Metric; MPN ERA-3AEB103V
U501, U502, U503, U504, U509: OPA376xxDBV; SOT-23-5; MPN OPA376AIDBVR
U505, U506: AD8421ARZ; SOIC-8_3.9x4.9mm_P1.27mm; MPN AD8421ARZ
U507: ADS131M04xPW; TSSOP-20_4.4x6.5mm_P0.65mm; MPN ADS131M04IPWR
U508: ISO7762FDBQ; SSOP-16_3.9x4.9mm_P0.635mm; MPN ISO7762FDBQ

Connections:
+3V3: C514.2, U508.1 (Vcc1); also elsewhere on the board
+3V3A: C502.1, C503.1, C504.1, C505.1, C506.1, C507.1, C510.1, C511.1, C512.1, C513.2, U501.5 (V+), U502.5 (V+), U503.5 (V+), U504.5 (V+), U505.8 (Vs+), U506.8 (Vs+), U507.1 (AVDD), U507.20 (DVDD), U508.16 (Vcc2), U509.5 (V+); also elsewhere on the board
-3V3A: C508.1, C509.1, C515.1, C516.1, C517.1, C518.1, C519.1, U501.2 (V-), U502.2 (V-), U503.2 (V-), U504.2 (V-), U505.5 (Vs-), U506.5 (Vs-), U509.2 (V-); also elsewhere on the board
/V&I_sense/ADC_DRDY: U508.7 (OUTF); also elsewhere on the board
/V&I_sense/AIN0P: U506.7, U507.3 (AIN0P)
/V&I_sense/AIN1P: U505.7, U507.6 (AIN1P)
/V&I_sense/AIN2P: U507.7 (AIN2P), U509.1, U509.4 (-)
/V&I_sense/CLK_MCO: U508.2 (INA); also elsewhere on the board
/V&I_sense/SPI.CS: U508.5 (IND); also elsewhere on the board
/V&I_sense/SPI.MISO: U508.6 (OUTE); also elsewhere on the board
/V&I_sense/SPI.MOSI: U508.4 (INC); also elsewhere on the board
/V&I_sense/SPI.SCLK: U508.3 (INB); also elsewhere on the board
/V&I_sense/cap: C501.1, U507.18 (CAP)
/V&I_sense/i_sense.I+: U504.3 (+); also elsewhere on the board
/V&I_sense/i_sense.I-: U503.3 (+); also elsewhere on the board
/V&I_sense/sense_iso_V+: R505.1, U502.1, U502.4 (-), U505.4 (+)
/V&I_sense/sense_iso_V-: R502.1, U501.1, U501.4 (-), U505.1 (-), U507.8 (AIN2N)
/V&I_sense/v_sense.V+: U502.3 (+); also elsewhere on the board
/V&I_sense/v_sense.V-: U501.3 (+); also elsewhere on the board
GND: C501.2, C502.2, C503.2, C504.2, C505.2, C506.2, C507.2, C508.2, C509.2, C510.2, C511.2, C512.2, C513.1, C515.2, C516.2, C517.2, C518.2, C519.2, R502.2, R504.2, R506.2, U505.6 (Ref), U506.6 (Ref), U507.2 (AGND), U507.4 (AIN0N), U507.5 (AIN1N), U507.19 (DGND), U508.9 (GND2); also elsewhere on the board
GNDPWR: C514.1, U508.8 (GND1); also elsewhere on the board
unnamed: R501.1, U505.2 (Rg)
unnamed: R501.2, U505.3 (Rg)
unnamed: R503.1, U506.2 (Rg)
unnamed: R503.2, U506.3 (Rg)
unnamed: R504.1, U503.1, U503.4 (-), U506.1 (-)
unnamed: U504.1, U504.4 (-), U506.4 (+)
unnamed: U507.17 (CLKIN), U508.15 (OUTA)
unnamed: U507.16 (DIN), U508.13 (OUTC)
unnamed: U507.15 (DOUT), U508.11 (INE)
unnamed: U507.14 (SCLK), U508.14 (OUTB)
unnamed: U507.12 (~CS), U508.12 (OUTD)
unnamed: U507.13 (~DRDY), U508.10 (INF)
unnamed: R505.2, R506.1, U509.3 (+)

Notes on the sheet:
Temp sensor resistances
V/I Sense (PAGE 5)
Return path to gnd required per datasheet
Measures voltage drop over the temperature probe
Measures voltage drop over the shunt resistor to calculate current
Reads the voltage for diode style temperature probes which have a max voltage drop of >1.2V so a simple attenuator is used to bring it back into range
OPA376 acts as a buffer to protect the signal from the relatively high bias current of the AD8421
AD8421 is a low noise differential amplifier set to a gain of 200x due to the 50 ohm resistor to feed the ADC's voltage range of +-1.2V
24-bit differential adc with 4 channels plus galvanic isolation IC to keep digital and analog power seperate

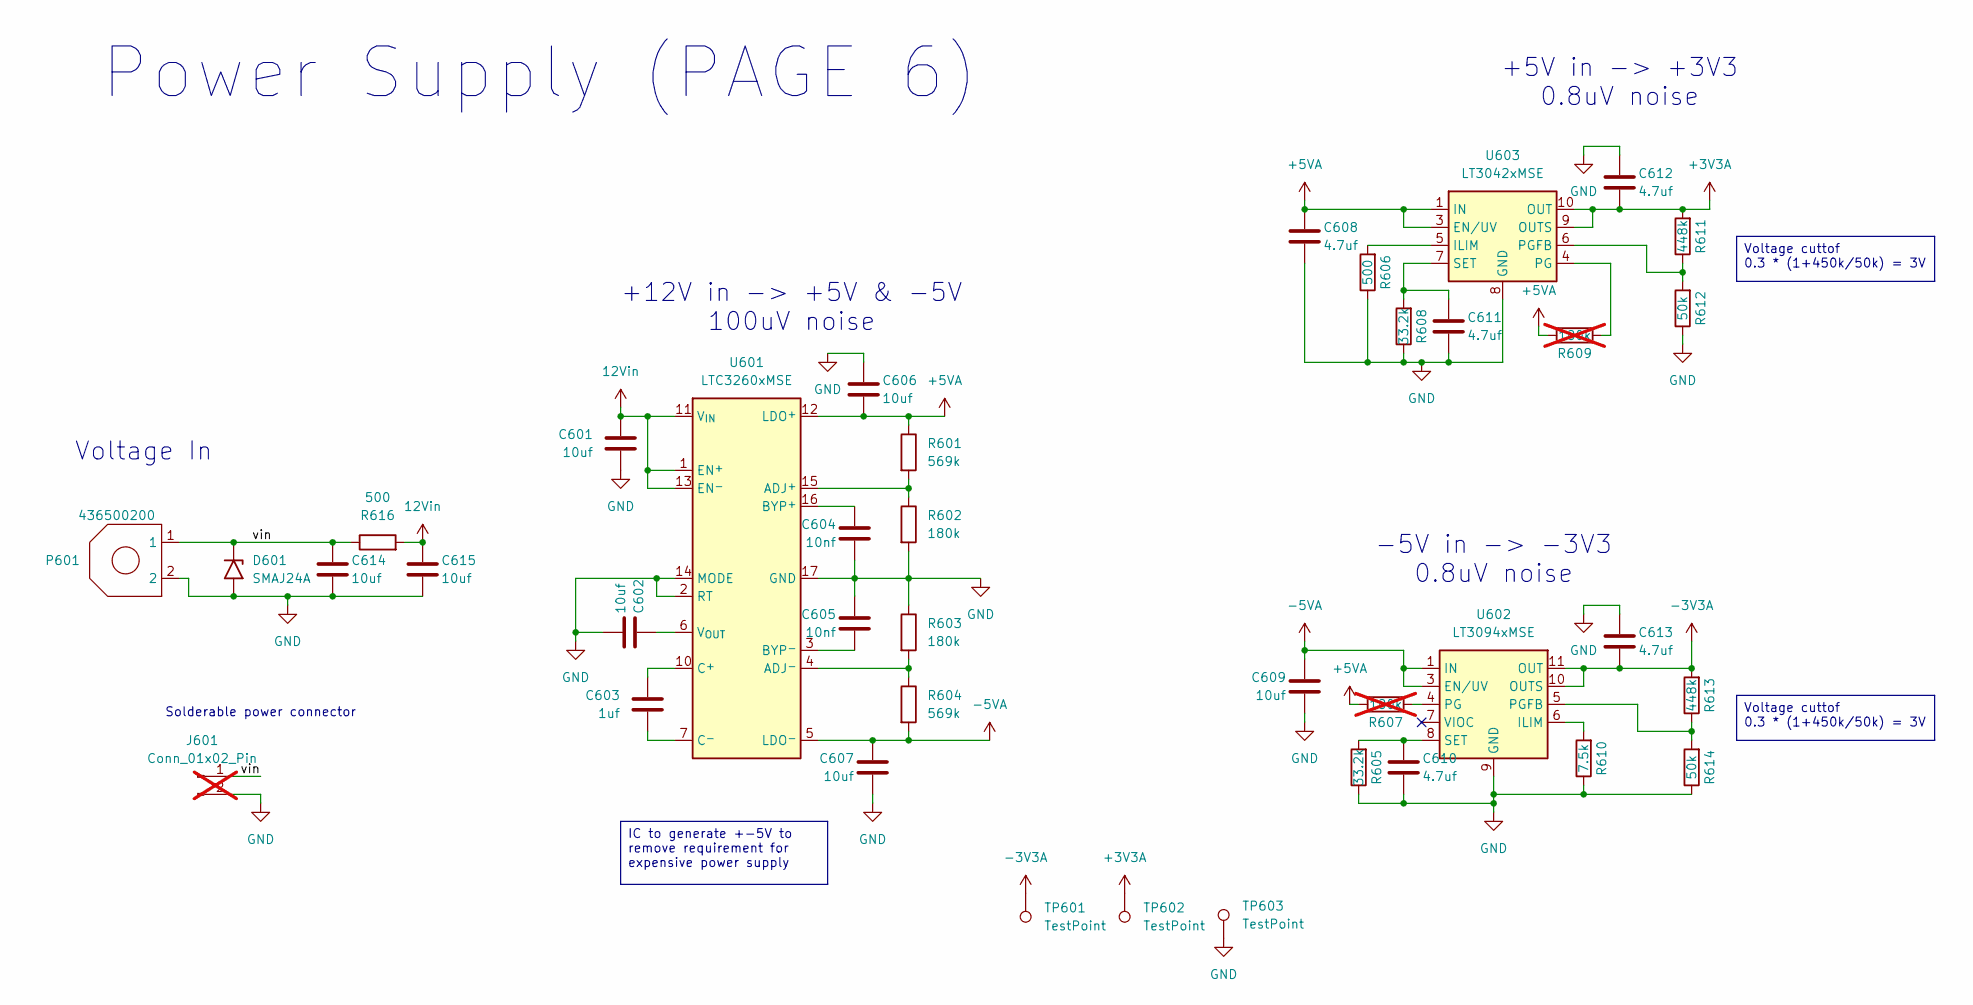
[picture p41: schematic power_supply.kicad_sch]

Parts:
C601, C602, C606, C607, C609, C614, C615: 10uf; C_0603_1608Metric; MPN GRM188R6YA106MA73D
C603: 1uf; C_0603_1608Metric; MPN C0603C105K4RACTU
C604, C605: 10nf; C_0603_1608Metric; MPN CL10B103KB8NNNC
C608, C610, C611, C612, C613: 4.7uf; C_0603_1608Metric; MPN CL10A475KO8NNNC
D601: SMAJ24A; D_SMA; MPN SMAJ24A
J601: Conn_01x02_Pin; PinHeader_1x02_P2.54mm_Vertical; not fitted
P601: 436500200; 436500200 2-pin; MPN 436500200
R601, R604: 569k; R_0603_1608Metric; MPN RN73H1JTTD5693B50
R602, R603: 180k; R_0603_1608Metric; MPN ERA-3AEB184V
R605, R608: 33.2k; R_0603_1608Metric; MPN ERA-3AEB3322V
R606, R616: 500; R_0603_1608Metric; MPN ERA-3AEB4990V
R607, R609: 180k; R_0603_1608Metric; MPN ERA-3AEB184V; not fitted
R610: 7.5k; R_0603_1608Metric; MPN ERA-3AEB752V
R611, R613: 448k; R_0603_1608Metric; MPN RT0603BRD07448KL
R612, R614: 50k; R_0603_1608Metric; MPN RT0603BRD0750KL
TP601, TP602, TP603: TestPoint; TestPoint_Pad_2.0x2.0mm
U601: LTC3260xMSE; MSOP-16-1EP_3x4.039mm_P0.5mm_EP1.651x2.845mm; MPN LTC3260EMSE#TRPBF
U602: LT3094xMSE; MSOP-12-1EP_3x4.039mm_P0.65mm_EP1.651x2.845mm; MPN LT3094EMSE#TRPBF
U603: LT3042xMSE; MSOP-10-1EP_3x3mm_P0.5mm_EP1.68x1.88mm; MPN LT3042EMSE#TRPBF

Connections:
12Vin: C601.1, C615.1, R616.2, U601.1 (EN^{+}), U601.11 (V_{IN}), U601.13 (EN^{-})
+3V3A: C612.2, R611.2, TP602.1 (1_1), U603.9 (OUTS), U603.10 (OUT); also elsewhere on the board
+5VA: C606.2, C608.1, R601.1, R607.2, R609.2, U601.12 (LDO^{+}), U603.1 (IN), U603.2 (IN), U603.3 (EN/UV)
-3V3A: C613.2, R613.2, TP601.1 (1_1), U602.10 (OUTS), U602.11 (OUT), U602.12 (OUT); also elsewhere on the board
-5VA: C607.1, C609.1, R604.2, U601.5 (LDO^{-}), U602.1 (IN), U602.2 (IN), U602.3 (EN/UV), U602.13 (IN)
/power_supply/vin: C614.1, D601.1 (A1), J601.1, P601.1, R616.1
GND: C601.2, C602.2, C604.2, C605.1, C606.1, C607.2, C608.2, C609.2, C610.2, C611.2, C612.1, C613.1, C614.2, C615.2, D601.2 (A2), J601.2, P601.2, R602.2, R603.1, R605.1, R606.1, R608.1, R610.1, R612.1, R614.1, TP603.1 (1_1), U601.2 (RT), U601.14 (MODE), U601.17 (GND), U602.9 (GND), U603.8 (GND), U603.11 (GND); also elsewhere on the board
unnamed: R601.2, R602.1, U601.15 (ADJ^{+})
unnamed: R603.2, R604.1, U601.4 (ADJ^{-})
unnamed: C604.1, U601.16 (BYP^{+})
unnamed: C605.2, U601.3 (BYP^{-})
unnamed: C603.1, U601.10 (C^{+})
unnamed: C603.2, U601.7 (C^{-})
unnamed: C602.1, U601.6 (V_{OUT})
unnamed: R610.2, U602.6 (ILIM)
unnamed: R607.1, U602.4 (PG)
unnamed: R613.1, R614.2, U602.5 (PGFB)
unnamed: C610.1, R605.2, U602.8 (SET)
unnamed: R606.2, U603.5 (ILIM)
unnamed: R609.1, U603.4 (PG)
unnamed: R611.1, R612.2, U603.6 (PGFB)
unnamed: C611.1, R608.2, U603.7 (SET)

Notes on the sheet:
+5V in -> +3V3 0.8uV noise
Voltage In
Power Supply (PAGE 6)
+12V in -> +5V & -5V 100uV noise
Solderable power connector
-5V in -> -3V3 0.8uV noise
Voltage cuttof 0.3 * (1+450k/50k) = 3V
IC to generate +-5V to remove requirement for expensive power supply

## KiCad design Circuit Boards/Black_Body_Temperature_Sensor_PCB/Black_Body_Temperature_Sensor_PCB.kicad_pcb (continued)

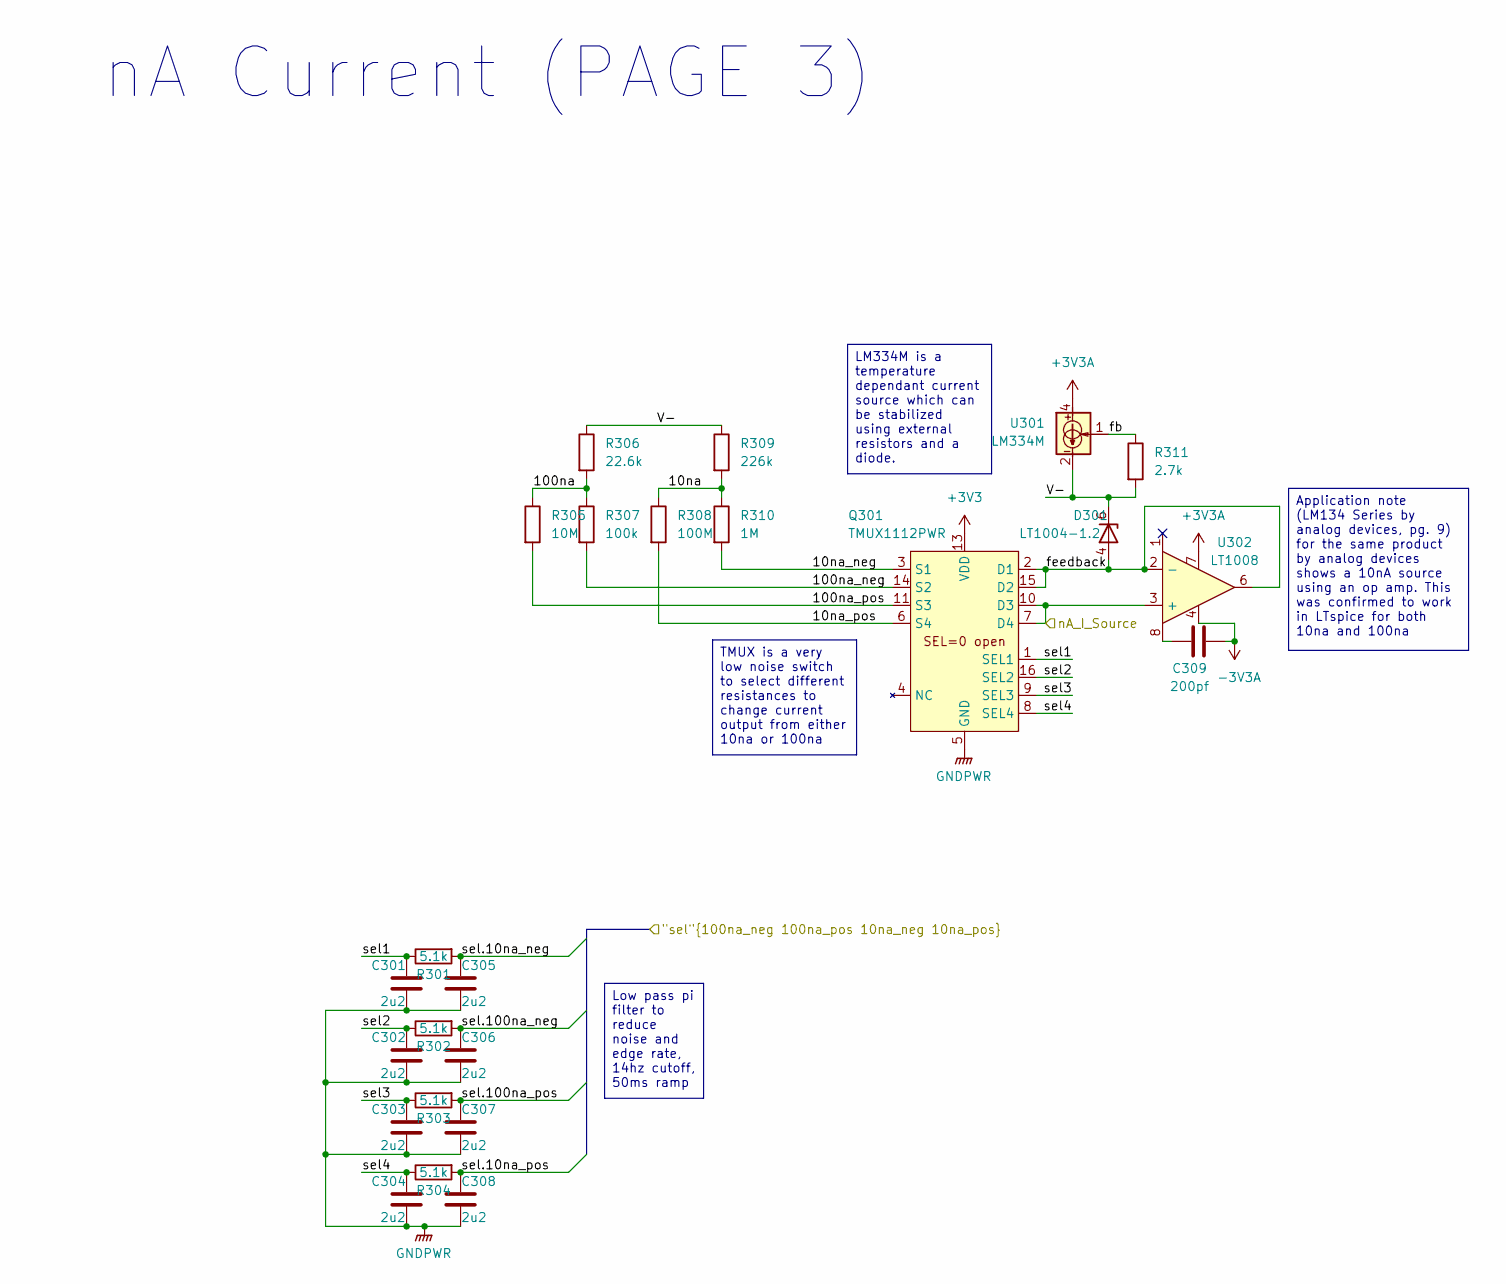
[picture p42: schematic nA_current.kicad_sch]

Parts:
C301, C302, C303, C304, C305, C306, C307, C308: 2u2; C_0402_1005Metric; MPN GRM155R61E225ME15D
C309: 200pf; C_0603_1608Metric; MPN CL10C201JB8NNNC
D301: LT1004-1.2; SOIC-8_3.9x4.9mm_P1.27mm; MPN LT1004CS8-1.2#TRPBF
Q301: TMUX1112PWR; TSSOP-16_4.4x5mm_P0.65mm; MPN TMUX1112PWR
R301, R302, R303, R304: 5.1k; R_0402_1005Metric; MPN RT0402BRD075K1L
R305: 10M; R_0603_1608Metric; MPN CRCW060310M0DHEAP
R306: 22.6k; R_0603_1608Metric; MPN ERA-3AEB2262V
R307: 100k; R_0603_1608Metric; MPN ERA-3AEB104V
R308: 100M; R_0603_1608Metric; MPN HVC0603T1006FET
R309: 226k; R_0603_1608Metric; MPN ERA-3AEB2263V
R310: 1M; R_0603_1608Metric; MPN RN73H1JTTD1004B25
R311: 2.7k; R_0603_1608Metric; MPN ERA-3AEB272V
U301: LM334M; SOIC-8_3.9x4.9mm_P1.27mm; MPN LM334M
U302: LT1008; SOIC-8_3.9x4.9mm_P1.27mm; MPN LT1008S8#PBF

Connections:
+3V3: Q301.13 (VDD); also elsewhere on the board
+3V3A: U301.4, U302.7; also elsewhere on the board
-3V3A: C309.2, U302.4; also elsewhere on the board
/micrcontroller/sel.10na_neg: C305.1, R301.2; also elsewhere on the board
/micrcontroller/sel.10na_pos: C308.1, R304.2; also elsewhere on the board
/micrcontroller/sel.100na_neg: C306.1, R302.2; also elsewhere on the board
/micrcontroller/sel.100na_pos: C307.1, R303.2; also elsewhere on the board
/nA_current/10na: R308.1, R309.2, R310.1
/nA_current/10na_neg: Q301.3 (S1), R310.2
/nA_current/10na_pos: Q301.6 (S4), R308.2
/nA_current/100na: R305.1, R306.2, R307.1
/nA_current/100na_neg: Q301.14 (S2), R307.2
/nA_current/100na_pos: Q301.11 (S3), R305.2
/nA_current/V-: D301.6, D301.8, R306.1, R309.1, R311.2, U301.2, U301.3, U301.6, U301.7
/nA_current/fb: R311.1, U301.1
/nA_current/feedback: D301.4, Q301.2 (D1), Q301.15 (D2), U302.2 (-), U302.6
/nA_current/nA_I_Source: Q301.7 (D4), Q301.10 (D3), U302.3 (+); also elsewhere on the board
/nA_current/sel1: C301.1, Q301.1 (SEL1), R301.1
/nA_current/sel2: C302.1, Q301.16 (SEL2), R302.1
/nA_current/sel3: C303.1, Q301.9 (SEL3), R303.1
/nA_current/sel4: C304.1, Q301.8 (SEL4), R304.1
GNDPWR: C301.2, C302.2, C303.2, C304.2, C305.2, C306.2, C307.2, C308.2, Q301.5 (GND); also elsewhere on the board
unnamed: C309.1, U302.8

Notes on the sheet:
nA Current (PAGE 3)
Application note (LM134 Series by analog devices, pg. 9) for the same product by analog devices shows a 10nA source using an op amp. This was confirmed to work in LTspice for both 10na and 100na
LM334M is a temperature dependant current source which can be stabilized using external resistors and a diode.
TMUX is a very low noise switch to select different resistances to change current output from either 10na or 100na
Low pass pi filter to reduce noise and edge rate, 14hz cutoff, 50ms ramp

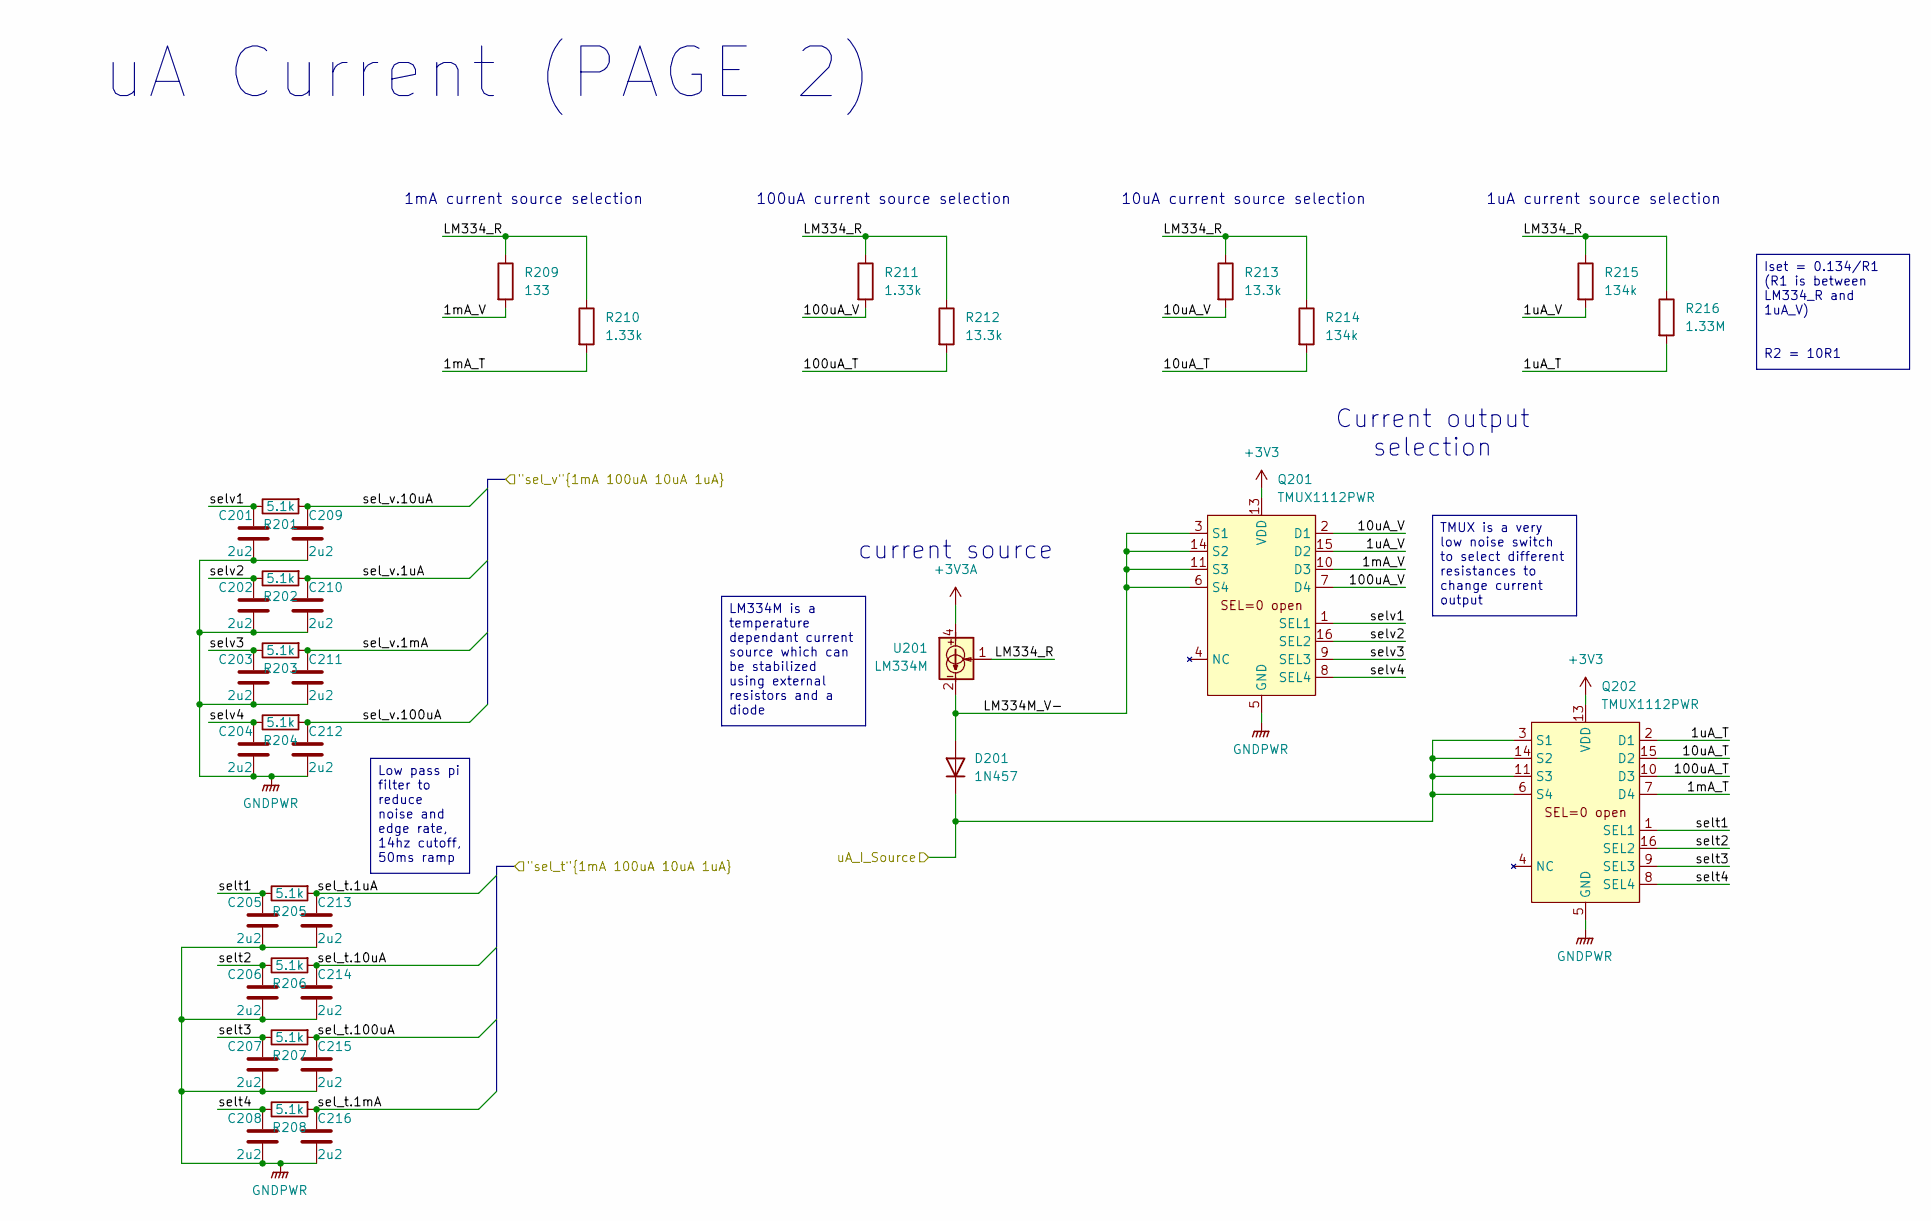
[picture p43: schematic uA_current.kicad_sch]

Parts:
C201, C202, C203, C204, C205, C206, C207, C208, C209, C210, C211, C212, C213, C214, C215, C216: 2u2; C_0402_1005Metric; MPN GRM155R61E225ME15D
D201: 1N457; D_DO-35_SOD27_P7.62mm_Horizontal; MPN 1N457
Q201, Q202: TMUX1112PWR; TSSOP-16_4.4x5mm_P0.65mm; MPN TMUX1112PWR
R201, R202, R203, R204, R205, R206, R207, R208: 5.1k; R_0402_1005Metric; MPN RT0402BRD075K1L
R209: 133; R_0603_1608Metric; MPN RQ73C1J133RBTD
R210, R211: 1.33k; R_0603_1608Metric; MPN ERA-3AEB1331V
R212, R213: 13.3k; R_0603_1608Metric; MPN ERA-3AEB1332V
R214, R215: 134k; R_0603_1608Metric; MPN ERA-3AEB1333V
R216: 1.33M; R_0603_1608Metric; MPN RK73H1JTTD1334F
U201: LM334M; SOIC-8_3.9x4.9mm_P1.27mm; MPN LM334M

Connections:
+3V3: Q201.13 (VDD), Q202.13 (VDD); also elsewhere on the board
+3V3A: U201.4; also elsewhere on the board
/micrcontroller/sel_t.1mA: C216.1, R208.2; also elsewhere on the board
/micrcontroller/sel_t.1uA: C213.1, R205.2; also elsewhere on the board
/micrcontroller/sel_t.10uA: C214.1, R206.2; also elsewhere on the board
/micrcontroller/sel_t.100uA: C215.1, R207.2; also elsewhere on the board
/micrcontroller/sel_v.1mA: C211.1, R203.2; also elsewhere on the board
/micrcontroller/sel_v.1uA: C210.1, R202.2; also elsewhere on the board
/micrcontroller/sel_v.10uA: C209.1, R201.2; also elsewhere on the board
/micrcontroller/sel_v.100uA: C212.1, R204.2; also elsewhere on the board
/sensor_interface/uA_I_Source: D201.1 (K), Q202.3 (S1), Q202.6 (S4), Q202.11 (S3), Q202.14 (S2); also elsewhere on the board
/uA_current/1mA_T: Q202.7 (D4), R210.2
/uA_current/1mA_V: Q201.10 (D3), R209.2
/uA_current/1uA_T: Q202.2 (D1), R216.2
/uA_current/1uA_V: Q201.15 (D2), R215.2
/uA_current/10uA_T: Q202.15 (D2), R214.2
/uA_current/10uA_V: Q201.2 (D1), R213.2
/uA_current/100uA_T: Q202.10 (D3), R212.2
/uA_current/100uA_V: Q201.7 (D4), R211.2
/uA_current/LM334M_V-: D201.2 (A), Q201.3 (S1), Q201.6 (S4), Q201.11 (S3), Q201.14 (S2), U201.2, U201.3, U201.6, U201.7
/uA_current/LM334_R: R209.1, R210.1, R211.1, R212.1, R213.1, R214.1, R215.1, R216.1, U201.1
/uA_current/selt1: C205.1, Q202.1 (SEL1), R205.1
/uA_current/selt2: C206.1, Q202.16 (SEL2), R206.1
/uA_current/selt3: C207.1, Q202.9 (SEL3), R207.1
/uA_current/selt4: C208.1, Q202.8 (SEL4), R208.1
/uA_current/selv1: C201.1, Q201.1 (SEL1), R201.1
/uA_current/selv2: C202.1, Q201.16 (SEL2), R202.1
/uA_current/selv3: C203.1, Q201.9 (SEL3), R203.1
/uA_current/selv4: C204.1, Q201.8 (SEL4), R204.1
GNDPWR: C201.2, C202.2, C203.2, C204.2, C205.2, C206.2, C207.2, C208.2, C209.2, C210.2, C211.2, C212.2, C213.2, C214.2, C215.2, C216.2, Q201.5 (GND), Q202.5 (GND); also elsewhere on the board

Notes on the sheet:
current source
Current output selection
uA Current (PAGE 2)
100uA current source selection
10uA current source selection
1mA current source selection
1uA current source selection
LM334M is a temperature dependant current source which can be stabilized using external resistors and a diode
Iset = 0.134/R1 (R1 is between LM334_R and 1uA_V) R2 = 10R1
Low pass pi filter to reduce noise and edge rate, 14hz cutoff, 50ms ramp
TMUX is a very low noise switch to select different resistances to change current output

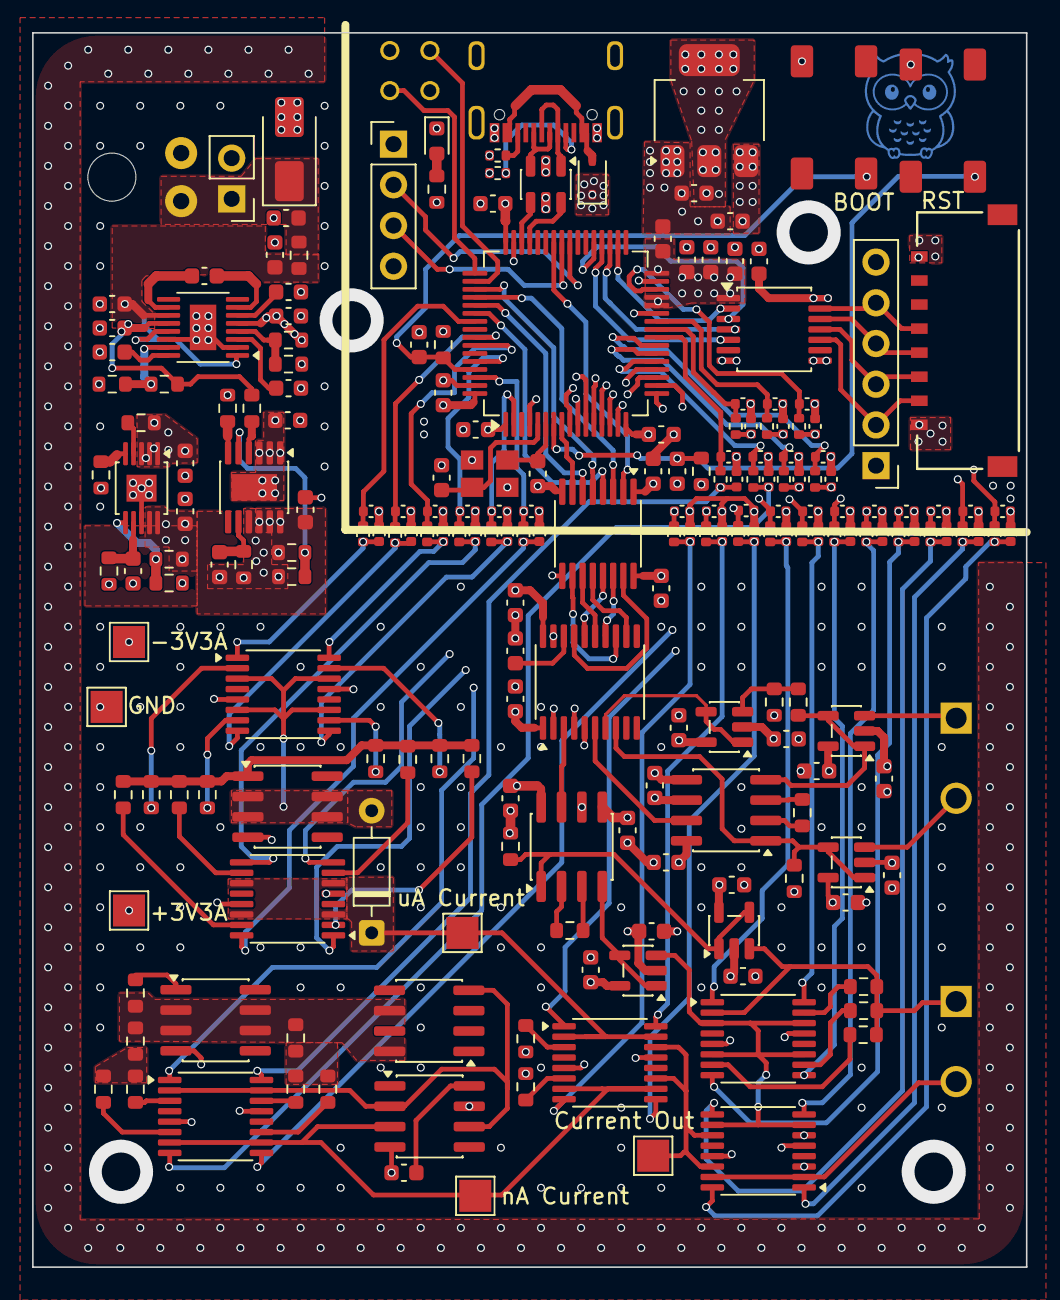
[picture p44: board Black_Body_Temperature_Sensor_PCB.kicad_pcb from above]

Board: 6 copper layers, 62.0 x 77.0 mm, 216 parts (0 on the bottom side), 155 nets.

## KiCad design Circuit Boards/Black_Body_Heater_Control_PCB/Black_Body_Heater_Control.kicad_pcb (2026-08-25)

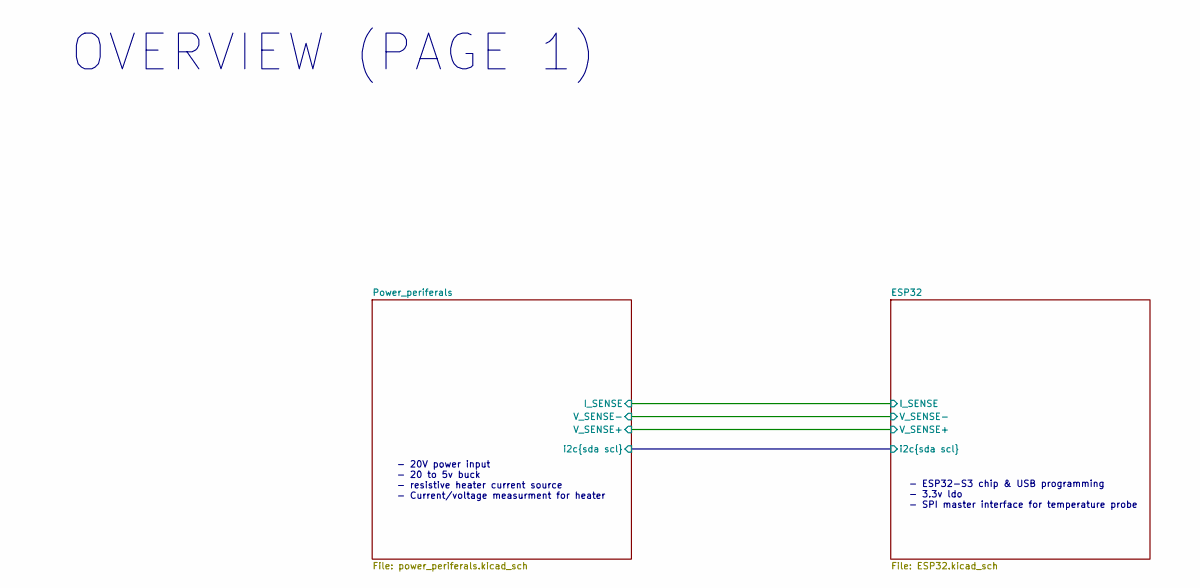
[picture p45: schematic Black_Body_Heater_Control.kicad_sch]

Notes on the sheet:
OVERVIEW (PAGE 1)
- ESP32-S3 chip & USB programming - 3.3v ldo - SPI master interface for temperature probe
- 20V power input - 20 to 5v buck - resistive heater current source - Current/voltage measurment for heater

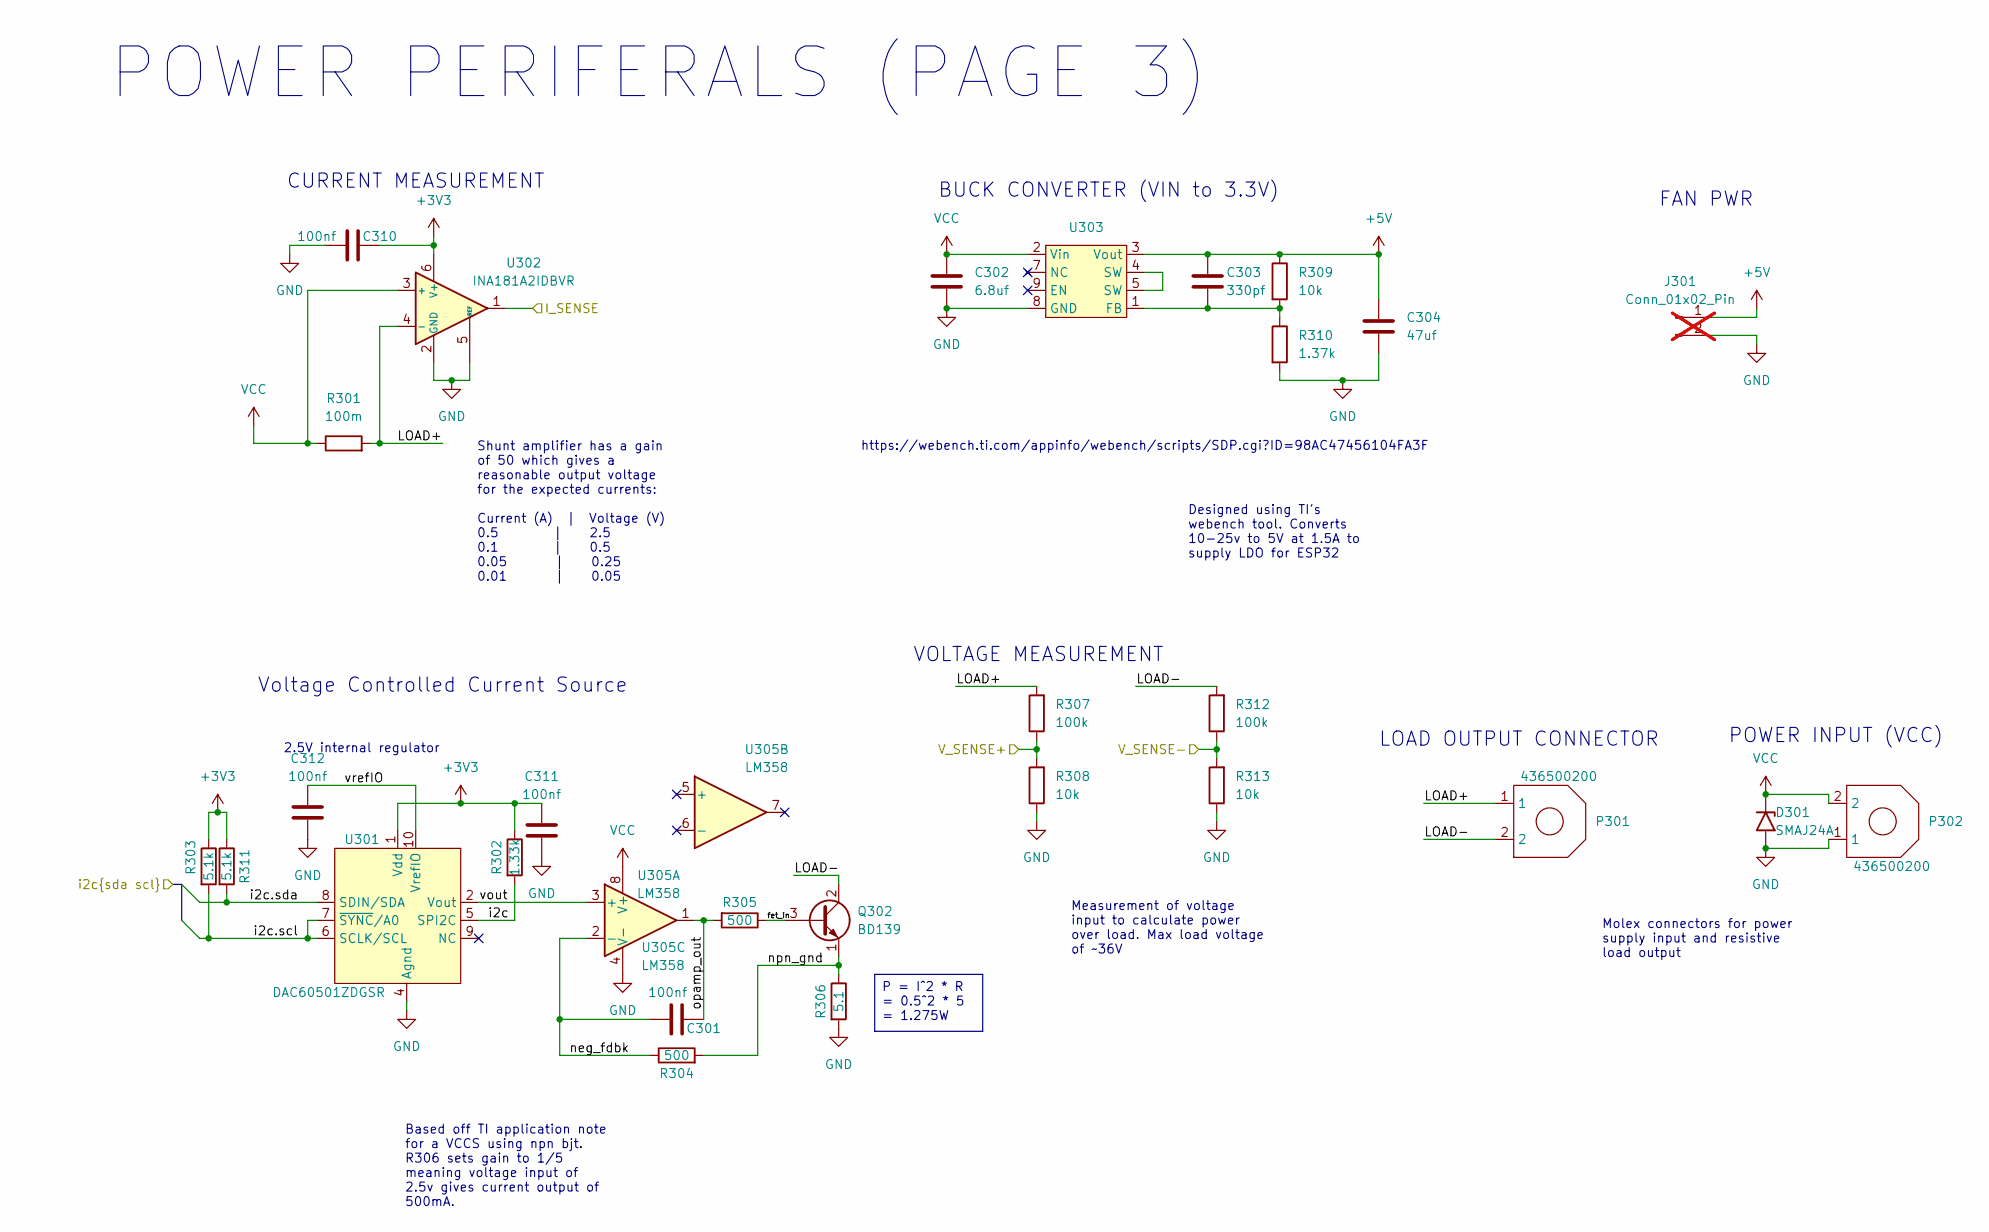
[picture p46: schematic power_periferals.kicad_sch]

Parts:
C301, C310, C311, C312: 100nf; C_0603_1608Metric; MPN CL10B104KB8NNNC
C302: 6.8uf; C_0603_1608Metric; MPN C1608X5R1E685K080AC
C303: 330pf; C_0603_1608Metric; MPN C0603C331J5GACTU
C304: 47uf; C_1210_3225Metric; MPN GRM32EC81C476KE15L
D301: SMAJ24A; D_SMA; MPN SMAJ24A
J301: Conn_01x02_Pin; PinHeader_1x02_P1.27mm_Vertical; not fitted
P301, P302: 436500200; 436500200 2-pin; MPN 436500200
Q302: BD139; TO-126-3_Vertical; MPN BD139
R301: 100m; R_0805_2012Metric; MPN RCWE0805R100FKEA
R302: 1.33k; R_0603_1608Metric; MPN ERA-3AEB1331V
R303, R311: 5.1k; R_0402_1005Metric; MPN RT0402BRD075K1L
R304, R305: 500; R_0603_1608Metric; MPN ERA-3AEB4990V
R306: 5.1; R_2512_6332Metric; MPN CRM2512-FX-5R10ELF
R307, R312: 100k; R_0603_1608Metric; MPN ERA-3AEB104V
R308, R309, R313: 10k; R_0603_1608Metric; MPN ERA-3AEB103V
R310: 1.37k; R_0603_1608Metric; MPN ERJ-3EKF1371V
U301: DAC60501ZDGSR; TSSOP-10_3x3mm_P0.5mm; MPN DAC60501ZDGSR
U302: INA181A2IDBVR; SOT-23-6; MPN INA181A2IDBVR
U303: TPSM84209; MPN TPSM84209RKHR
U305: LM358; SOIC-8_3.9x4.9mm_P1.27mm; MPN LM358BAIDR

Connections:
+3V3: C310.2, C311.2, R302.1, R303.1, R311.1, U301.1 (Vdd), U302.6 (V+); also elsewhere on the board
+5V: C303.1, C304.1, J301.1, R309.1, U303.3 (Vout); also elsewhere on the board
/ESP32/I_SENSE: U302.1; also elsewhere on the board
/ESP32/V_SENSE+: R307.1, R308.2; also elsewhere on the board
/ESP32/V_SENSE-: R312.1, R313.2; also elsewhere on the board
/ESP32/i2c.scl: R303.2, U301.6 (SCLK/SCL), U301.7 (~SYNC/A0); also elsewhere on the board
/ESP32/i2c.sda: R311.2, U301.8 (SDIN/SDA); also elsewhere on the board
/Power_periferals/LOAD+: P301.1, R301.2, R307.2, U302.4 (-)
/Power_periferals/LOAD-: P301.2, Q302.2 (C), R312.2
/Power_periferals/fet_in: Q302.3 (B), R305.1
/Power_periferals/i2c: R302.2, U301.5 (SPI2C)
/Power_periferals/neg_fdbk: C301.1, R304.1, U305.2 (-)
/Power_periferals/npn_gnd: Q302.1 (E), R304.2, R306.1
/Power_periferals/opamp_out: C301.2, R305.2, U305.1
/Power_periferals/vout: U301.2 (Vout), U305.3 (+)
/Power_periferals/vrefIO: C312.2, U301.10 (VrefIO)
GND: C302.2, C304.2, C310.1, C311.1, C312.1, D301.2 (A2), J301.2, P302.1, R306.2, R308.1, R310.2, R313.1, U301.4 (Agnd), U302.2 (GND), U302.5 (REF), U303.8 (GND), U305.4 (V-); also elsewhere on the board
unnamed: C303.2, R309.2, R310.1, U303.1 (FB)
unnamed: U303.4 (SW), U303.5 (SW)
VCC: C302.1, D301.1 (A1), P302.2, R301.1, U302.3 (+), U303.2 (Vin), U305.8 (V+)

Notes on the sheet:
https://webench.ti.com/appinfo/webench/scripts/SDP.cgi?ID=98AC47456104FA3F
POWER INPUT (VCC)
BUCK CONVERTER (VIN to 3.3V)
VOLTAGE MEASUREMENT
FAN PWR
POWER PERIFERALS (PAGE 3)
2.5V internal regulator
Voltage Controlled Current Source
CURRENT MEASUREMENT
LOAD OUTPUT CONNECTOR
Molex connectors for power supply input and resistive load output
Designed using TI's webench tool. Converts 10-25v to 5V at 1.5A to supply LDO for ESP32
Shunt amplifier has a gain of 50 which gives a reasonable output voltage for the expected currents: Current (A) | Voltage (V) 0.5 | 2.5 0.1 | 0.5 0.05 | 0.25 0.01 | 0.05
Measurement of voltage input to calculate power over load. Max load voltage of ~36V
P = I^2 * R = 0.5^2 * 5 = 1.275W
Based off TI application note for a VCCS using npn bjt. R306 sets gain to 1/5 meaning voltage input of 2.5v gives current output of 500mA.

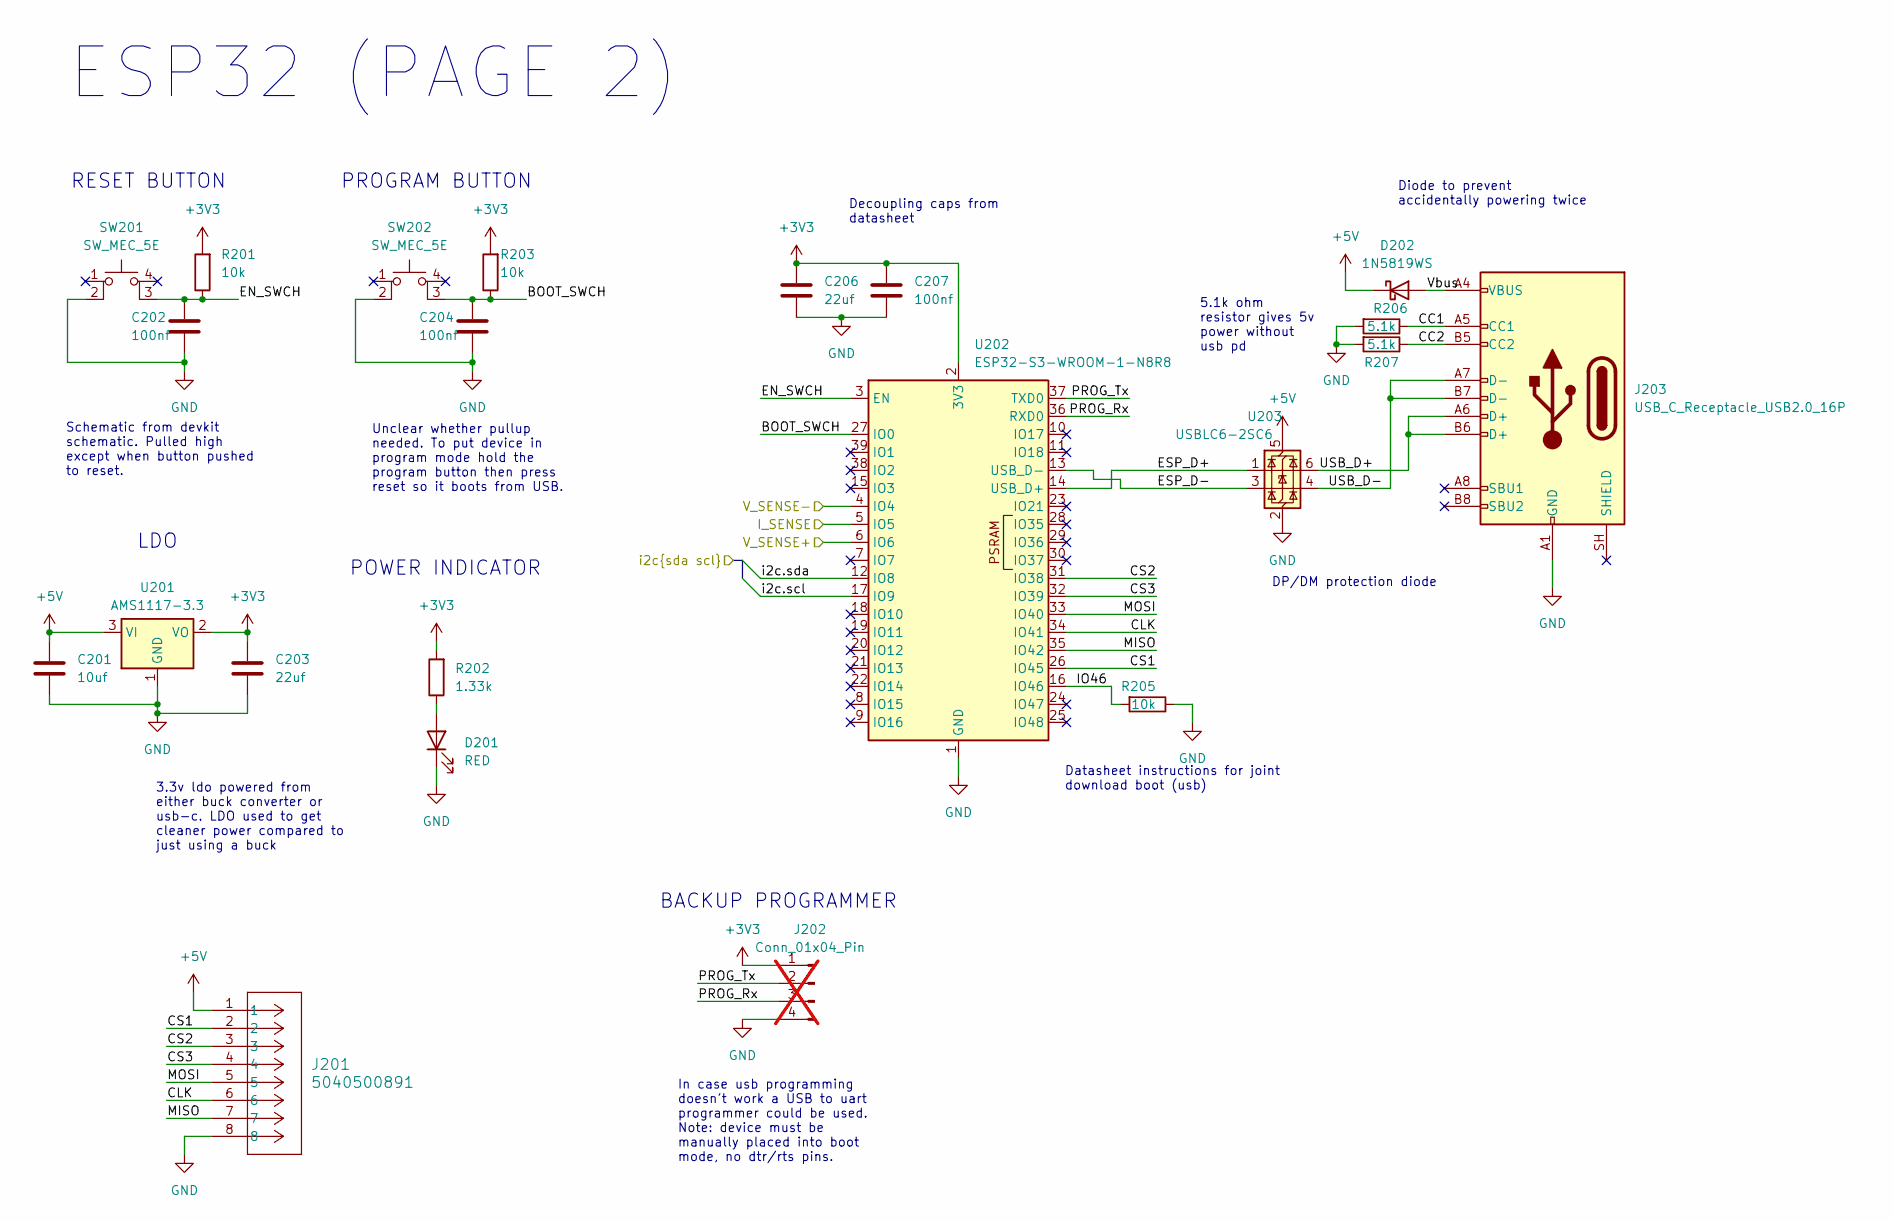
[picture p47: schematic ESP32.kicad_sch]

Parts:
C201: 10uf; C_0603_1608Metric; MPN GRM188R6YA106MA73D
C202, C204, C207: 100nf; C_0603_1608Metric; MPN CL10B104KB8NNNC
C203, C206: 22uf; C_0603_1608Metric; MPN CL10A226MP8NUNE
D201: RED; LED_0603_1608Metric; MPN LTST-C191KRKT
D202: 1N5819WS; D_SOD-323; MPN 1N5819WS
J201: 5040500891; CONN_5040500891_MOL; MPN 5040500891
J202: Conn_01x04_Pin; PinHeader_1x04_P1.00mm_Vertical; not fitted
J203: USB_C_Receptacle_USB2.0_16P; UJ20-C-H-G-SMT-1-P16-TR; MPN UJ20-C-H-G-SMT-1-P16-TR
R201, R203, R205: 10k; R_0603_1608Metric; MPN ERA-3AEB103V
R202: 1.33k; R_0603_1608Metric; MPN ERA-3AEB1331V
R206, R207: 5.1k; R_0402_1005Metric; MPN RT0402BRD075K1L
SW201, SW202: SW_MEC_5E; 430471035826; MPN SW_MEC_5E
U201: AMS1117-3.3; SOT-223-3_TabPin2; MPN AMS1117-3.3
U202: ESP32-S3-WROOM-1-N8R8; ESP32-S3-WROOM-1; MPN ESP32-S3-WROOM-1-N8R8
U203: USBLC6-2SC6; SOT-23-6; MPN USBLC6-2SC6

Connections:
+3V3: C203.1, C206.1, C207.1, J202.1, R201.2, R202.2, R203.2, U201.2 (VO), U202.2 (3V3); also elsewhere on the board
+5V: C201.1, D202.1 (K), J201.1, U201.3 (VI), U203.5 (VBUS); also elsewhere on the board
/ESP32/BOOT_SWCH: C204.1, R203.1, SW202.3 (K), U202.27 (IO0)
/ESP32/CC1: J203.A5 (CC1), R206.1
/ESP32/CC2: J203.B5 (CC2), R207.1
/ESP32/CLK: J201.6, U202.34 (IO41)
/ESP32/CS1: J201.2, U202.26 (IO45)
/ESP32/CS2: J201.3, U202.31 (IO38)
/ESP32/CS3: J201.4, U202.32 (IO39)
/ESP32/EN_SWCH: C202.1, R201.1, SW201.3 (K), U202.3 (EN)
/ESP32/ESP_D+: U202.14 (USB_D+), U203.1 (I/O1)
/ESP32/ESP_D-: U202.13 (USB_D-), U203.3 (I/O2)
/ESP32/IO46: R205.2, U202.16 (IO46)
/ESP32/I_SENSE: U202.5 (IO5); also elsewhere on the board
/ESP32/MISO: J201.7, U202.35 (IO42)
/ESP32/MOSI: J201.5, U202.33 (IO40)
/ESP32/PROG_Rx: J202.3, U202.36 (RXD0)
/ESP32/PROG_Tx: J202.2, U202.37 (TXD0)
/ESP32/USB_D+: J203.A6 (D+), J203.B6 (D+), U203.6 (I/O1)
/ESP32/USB_D-: J203.A7 (D-), J203.B7 (D-), U203.4 (I/O2)
/ESP32/V_SENSE+: U202.6 (IO6); also elsewhere on the board
/ESP32/V_SENSE-: U202.4 (IO4); also elsewhere on the board
/ESP32/Vbus: D202.2 (A), J203.A4 (VBUS), J203.A9 (VBUS), J203.B4 (VBUS), J203.B9 (VBUS)
/ESP32/i2c.scl: U202.17 (IO9); also elsewhere on the board
/ESP32/i2c.sda: U202.12 (IO8); also elsewhere on the board
GND: C201.2, C202.2, C203.2, C204.2, C206.2, C207.2, D201.1 (K), J201.8, J202.4, J203.A1 (GND), J203.A12 (GND), J203.B1 (GND), J203.B12 (GND), R205.1, R206.2, R207.2, SW201.2, SW202.2, U201.1 (GND), U202.1 (GND), U202.40 (GND), U202.41 (GND), U203.2 (GND); also elsewhere on the board
unnamed: D201.2 (A), R202.1

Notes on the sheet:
POWER INDICATOR
RESET BUTTON
PROGRAM BUTTON
BACKUP PROGRAMMER
ESP32 (PAGE 2)
LDO
3.3v ldo powered from either buck converter or usb-c. LDO used to get cleaner power compared to just using a buck
Schematic from devkit schematic. Pulled high except when button pushed to reset.
Unclear whether pullup needed. To put device in program mode hold the program button then press reset so it boots from USB.
Datasheet instructions for joint download boot (usb)
Diode to prevent accidentally powering twice
Decoupling caps from datasheet
5.1k ohm resistor gives 5v power without usb pd
DP/DM protection diode
In case usb programming doesn't work a USB to uart programmer could be used. Note: device must be manually placed into boot mode, no dtr/rts pins.

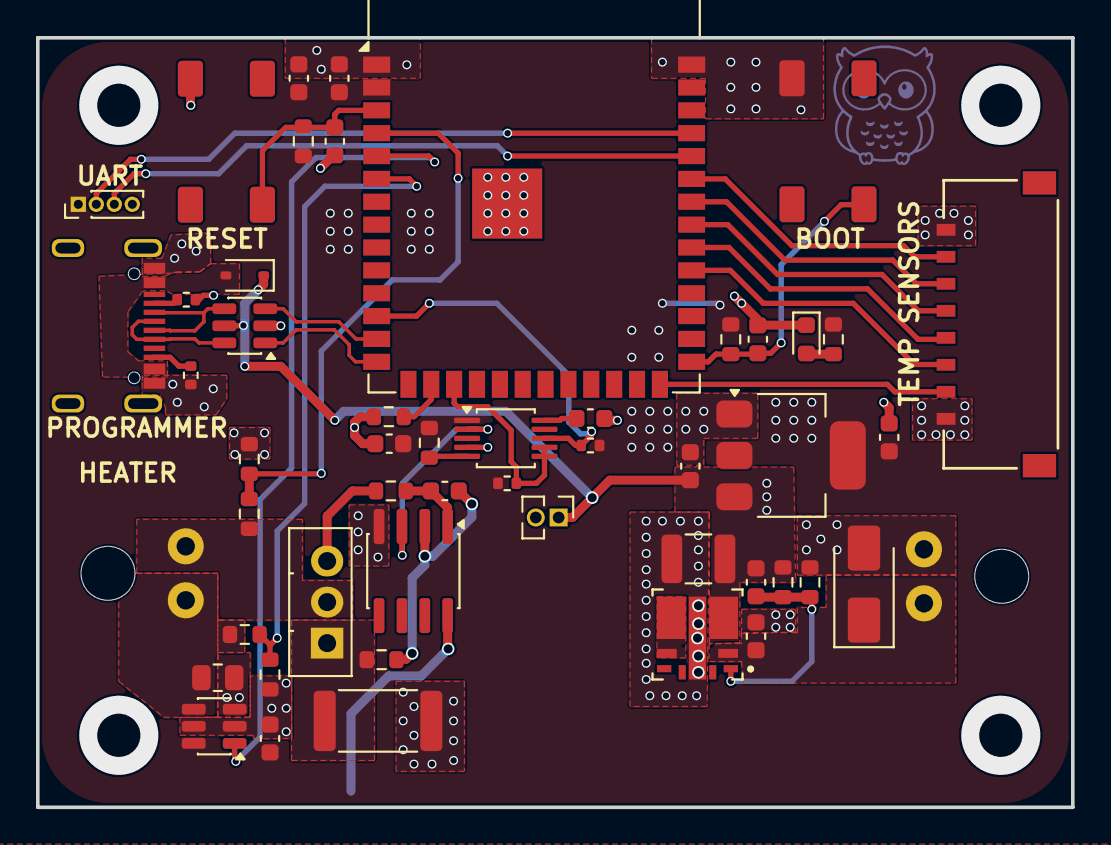
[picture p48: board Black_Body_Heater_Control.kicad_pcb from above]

Board: 2 copper layers, 57.5 x 42.8 mm, 51 parts (0 on the bottom side), 39 nets.

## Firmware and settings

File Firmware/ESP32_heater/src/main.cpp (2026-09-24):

#include "main.h"
#include "SegmentedCalibration.h"
#include <ArduinoJson.h>
#include <freertos/FreeRTOS.h>
#include <freertos/task.h>
#include <freertos/semphr.h>

//Wifi initilizations
IPAddress apIP(192,168,4,1);
IPAddress subnet(255,255,255,0);

DNSServer dns;
AsyncWebServer server(80);

SensorReading latestReading;

// Heater control state / feedback. Guarded by dataMutex, same as
// latestReading/gCal (see the FreeRTOS task / synchronization note
// below for why).
HeaterReading latestHeaterReading;
HeaterControl gHeater;

// DAC initilization
DAC60501 dac(I2C_ADDRESS_SCL);

// SPI communication with temp probe
STM32Sensor sensor(SPI_CS);

// ---------------------------------------------------------------------
// Profile / calibration state
// ---------------------------------------------------------------------
// A "profile" is a saved calibration: a small set of piecewise cubic
// segments (see SegmentedCalibration.h) mapping resistance -> temperature,
// e.g. transcribed/interpolated from a manufacturer data sheet such as the
// GR-300-AA table. Unlike an on-device least-squares fit, every
// coefficient and every segment's resistance range is set directly and
// edited as-is from the web UI, so live resistance readings can be
// converted to temperature locally without needing the browser to do any
// math.

static const char *PROFILES_DIR = "/profiles";
static const char *ACTIVE_PROFILE_FILE = "/active_profile.txt";

// Default calibration for a GR-300-AA-style sensor: 3 piecewise cubic
// segments in ln(R)->ln(T), matching the manufacturer's R-T table to
// within ~0.001 K. Seeded as the "GR-300-AA" profile on first boot only
// (see seedDefaultProfileIfMissing); fully editable afterward.
static const char *DEFAULT_PROFILE_NAME = "GR-300-AA";
static const CalSegment DEFAULT_CAL_SEGMENTS[3] = {
    // R >= 248.8 ohm (T <= 2 K)
    { 248.8f, 1.0e6f, -0.0091414284f, 0.2467387139f, -2.5443885697f, 8.7550629529f },
    // 33.2 ohm <= R < 248.8 ohm (2 K <= T <= 10 K)
    { 33.2f, 248.8f, 0.027577728f, -0.3426015171f, 0.5804353397f, 3.2875860941f },
    // R < 33.2 ohm (T >= 10 K)
    { 0.0f, 33.2f, -0.0910341581f, 0.5621404413f, -1.92412108f, 6.0572837321f },
};

SegmentedCalibration gCal;
String gActiveProfileName = "";

// ---------------------------------------------------------------------
// FreeRTOS task / synchronization
// ---------------------------------------------------------------------
// The STM32 SPI read (sensor.read()) can block for a little while waiting
// on the STM32 to clock data out. Doing that inline in Arduino's loop()
// (which shares a core with, and can starve, WiFi/TCP servicing) was
// causing the softAP to drop clients. sensorTask now owns all SPI polling
// and runs on its own core, so it can never stall WiFi or the DNS captive
// portal responder in loop(). dataMutex guards every field that both
// sensorTask (writer) and the async web server's request handlers
// (readers/writers, running on a different task) touch: latestReading,
// gCal, and gActiveProfileName.
static TaskHandle_t sensorTaskHandle = nullptr;
static TaskHandle_t heaterTaskHandle = nullptr;
static SemaphoreHandle_t dataMutex = nullptr;
static void sensorTask(void *pvParameters);
static void heaterTask(void *pvParameters);

// ---------------------------------------------------------------------
// Heater PID gain persistence
// ---------------------------------------------------------------------
// Only Kp/Ki/Kd are persisted (as "kp,ki,kd"); target temperature and
// manual-override state are intentionally session-only, per the web UI's
// requirements.
static const char *PID_CONFIG_FILE = "/pid_config.txt";

static void savePidConfig(float kp, float ki, float kd) {
  File f = LittleFS.open(PID_CONFIG_FILE, "w");
  if (!f) return;
  f.printf("%.6f,%.6f,%.6f", kp, ki, kd);
  f.close();
}

static bool loadPidConfig(float &kp, float &ki, float &kd) {
  File f = LittleFS.open(PID_CONFIG_FILE, "r");
  if (!f) return false;
  String line = f.readString();
  f.close();
  int c1 = line.indexOf(',');
  int c2 = (c1 == -1) ? -1 : line.indexOf(',', c1 + 1);
  if (c1 == -1 || c2 == -1) return false;
  kp = line.substring(0, c1).toFloat();
  ki = line.substring(c1 + 1, c2).toFloat();
  kd = line.substring(c2 + 1).toFloat();
  return true;
}

// Only called from setup(), before heaterTask is created, so no locking needed.
static void restoreHeaterConfigOnBoot() {
  float kp, ki, kd;
  if (loadPidConfig(kp, ki, kd)) {
    gHeater.pidKp = kp;
    gHeater.pidKi = ki;
    gHeater.pidKd = kd;
  }
}

static String profileSegPath(const String &name) {
  return String(PROFILES_DIR) + "/" + name + ".seg";
}

// Validates and persists a segment set as profile `name`. Returns true on
// success (segments rejected as invalid are never written).
static bool saveSegmentsForProfile(const String &name, const CalSegment *segments, int numSegments) {
  SegmentedCalibration cal;
  if (!cal.setSegments(segments, numSegments)) return false;

  char buf[512];
  size_t written = cal.serialize(buf, sizeof(buf));
  if (written == 0) return false;

  File f = LittleFS.open(profileSegPath(name), "w");
  if (!f) return false;
  f.print(buf);
  f.close();
  return true;
}

static bool loadCalibrationForProfile(const String &name) {
  File f = LittleFS.open(profileSegPath(name), "r");
  if (!f) return false;
  String contents = f.readString();
  f.close();
  return gCal.deserialize(contents.c_str());
}

// Called from the async web server's request-handler context (a different
// task than sensorTask), so gActiveProfileName/gCal are updated under
// dataMutex — sensorTask reads both on every SPI sample.
static void setActiveProfile(const String &name) {
  if (dataMutex != nullptr && xSemaphoreTake(dataMutex, portMAX_DELAY) == pdTRUE) {
    gActiveProfileName = name;
    loadCalibrationForProfile(name); // ok if it fails; gCal just stays invalid
    xSemaphoreGive(dataMutex);
  } else {
    // dataMutex not created yet (e.g. called during early boot) — safe to
    // touch directly since sensorTask can't be running yet at that point.
    gActiveProfileName = name;
    loadCalibrationForProfile(name);
  }
  File f = LittleFS.open(ACTIVE_PROFILE_FILE, "w");
  if (f) {
    f.print(name);
    f.close();
  }
}

// Only called from setup(), before sensorTask is created, so no locking
// needed here.
static void restoreActiveProfileOnBoot() {
  File f = LittleFS.open(ACTIVE_PROFILE_FILE, "r");
  if (!f) return;
  String name = f.readString();
  f.close();
  name.trim();
  if (name.length() > 0) {
    gActiveProfileName = name;
    loadCalibrationForProfile(name);
  }
}

// Creates the built-in "GR-300-AA" profile and marks it active, but only on
// a device's very first boot (i.e. no active-profile record exists yet).
// Gives the device a working calibration out of the box while leaving
// every later boot's user-edited profiles untouched.
static void seedDefaultProfileIfMissing() {
  if (LittleFS.exists(ACTIVE_PROFILE_FILE)) return;
  if (!saveSegmentsForProfile(DEFAULT_PROFILE_NAME, DEFAULT_CAL_SEGMENTS, 3)) return;
  File f = LittleFS.open(ACTIVE_PROFILE_FILE, "w");
  if (f) {
    f.print(DEFAULT_PROFILE_NAME);
    f.close();
  }
}

// Parses a JSON body of the form {"segments":[{"rMin":..,"rMax":..,
// "c0":..,"c1":..,"c2":..,"c3":..}, ...]} as sent by the web UI's segment
// table. Segments with a missing/non-numeric field or rMax <= rMin are
// silently skipped. Returns the number of segments parsed into `out`
// (capped at maxSegments), or 0 on a malformed body.
static int parseSegmentsJson(const char *json, CalSegment *out, int maxSegments) {
  JsonDocument doc;
  if (deserializeJson(doc, json) != DeserializationError::Ok) return 0;

  JsonArrayConst segs = doc["segments"].as<JsonArrayConst>();
  if (segs.isNull()) return 0;

  int n = 0;
  for (JsonObjectConst seg : segs) {
    if (n >= maxSegments) break;
    if (!seg["rMin"].is<float>() || !seg["rMax"].is<float>() ||
        !seg["c0"].is<float>() || !seg["c1"].is<float>() ||
        !seg["c2"].is<float>() || !seg["c3"].is<float>()) {
      continue;
    }
    float rMin = seg["rMin"];
    float rMax = seg["rMax"];
    if (!(rMax > rMin)) continue;

    out[n].rMin = rMin;
    out[n].rMax = rMax;
    out[n].c0 = seg["c0"];
    out[n].c1 = seg["c1"];
    out[n].c2 = seg["c2"];
    out[n].c3 = seg["c3"];
    n++;
  }
  return n;
}

void setup() {
  // put your setup code here, to run once:
  Serial.begin(115200);
  delay(1000);

  // Created before anything else touches latestReading/gCal.
  dataMutex = xSemaphoreCreateMutex();

  dac.init(SDA_PIN, SCL_PIN, STANDARD_MODE);

  // Set to zero
  set_output_current(0);
  
  // Initilize wifi
  wifi_setup();

  // Restore last-used calibration profile / fit, if any.
  restoreActiveProfileOnBoot();

  // Restore persisted PID gains, if any (target temp / manual override are
  // intentionally not persisted).
  restoreHeaterConfigOnBoot();

  // Initilize temperature probe SPI read
  sensor.begin();

  // Run SPI polling entirely on its own FreeRTOS task, pinned to core 0
  // (Arduino's setup()/loop() and the WiFi/lwIP stack effectively live on
  // core 1 by default). This is what stops a slow/blocking SPI transfer
  // from ever delaying dns.processNextRequest() or WiFi's own servicing —
  // the two are now fully independent tasks instead of sharing one loop.
  xTaskCreatePinnedToCore(
    sensorTask,        // task function
    "SensorTask",      // name (for debugging, e.g. in a task list dump)
    4096,               // stack size, in bytes
    nullptr,            // parameters
    1,                  // priority (above idle, below anything time-critical)
    &sensorTaskHandle,
    0                   // core 0
  );

  // Heater PID / manual-override control loop. Runs on core 1 (alongside
  // loop()'s networking housekeeping) at a modest 5 Hz, separate from
  // sensorTask's tight SPI polling loop on core 0.
  xTaskCreatePinnedToCore(
    heaterTask,
    "HeaterTask",
    4096,
    nullptr,
    1,
    &heaterTaskHandle,
    1                   // core 1
  );
}

void loop() {
  // loop() now does networking/captive-portal housekeeping ONLY. All SPI
  // sensor polling happens in sensorTask (see setup() and sensorTask()
  // below), so nothing here can ever be blocked by a slow SPI transfer.
  dns.processNextRequest();
  vTaskDelay(pdMS_TO_TICKS(10)); // yield to the scheduler; no need to spin
}

// Dedicated FreeRTOS task: polls the STM32 over SPI as fast as it can and
// publishes results into latestReading/gCal-derived temperature under
// dataMutex. Runs forever on core 0, independent of loop()/WiFi (core 1).
static void sensorTask(void *pvParameters) {
  (void)pvParameters;

  for (;;) {
    Sensor_Data data;
    if (sensor.read(&data) && data.resistance > 1.0 && data.resistance < 50000.0) {
      float temperature = NAN;

      if (xSemaphoreTake(dataMutex, portMAX_DELAY) == pdTRUE) {
        // resistance == 0 means no sensor is connected (or the reading is
        // otherwise invalid), so there's nothing to evaluate the
        // calibration against — report temperature as null rather than a
        // bogus extrapolated value.
        if (gCal.isValid() && data.resistance > 0.0f) {
          temperature = gCal.evaluate(data.resistance);
        }

        latestReading.current = data.current;
        latestReading.voltage = data.voltage;
        latestReading.resistance = data.resistance;
        // Convert resistance -> temperature locally using the active
        // calibration profile's piecewise segments, when one is loaded.
        // Falls back to NAN (reported as "temperature":null) if no
        // calibration is active yet, or the resistance falls outside every
        // configured segment, rather than silently reporting resistance as
        // if it were temperature.
        latestReading.temperature = temperature;

        // Debug-only raw fields, surfaced by the debug panel in the UI.
        latestReading.curSource = (uint8_t)data.cur_source;
        latestReading.curDirection = (uint8_t)data.current_direction;
        latestReading.shuntResistor = (uint8_t)data.shunt_resistor;

        xSemaphoreGive(dataMutex);
      }

      //Serial.print(data.resistance);
      //Serial.print(" ohm; ");
      //Serial.print(data.voltage, 6);
      //Serial.print(" mV; ");
      //Serial.print(data.current, 6);
      //Serial.println(" uA");
    }

    // sensor.read() already blocks briefly inside spi_slave_transmit's own
    // wait, but this small extra delay guarantees the task yields to the
    // scheduler on every iteration — including a run of instant
    // failed/empty reads — so it can never hog its core or trip the
    // watchdog.
    vTaskDelay(1);
  }
}

// Dedicated FreeRTOS task: reads heater board feedback (get_voltage() /
// get_current()), runs the temperature PID loop (when gHeater.running) or
// applies the manual-override current (when set and not running), and
// publishes the result via set_output_current(). Runs at a fixed ~5 Hz on
// core 1, independent of sensorTask's SPI polling on core 0.
static void heaterTask(void *pvParameters) {
  (void)pvParameters;

  const TickType_t periodTicks = pdMS_TO_TICKS(200); // 5 Hz
  float integral = 0.0f;
  float prevError = 0.0f;
  uint32_t prevTimeMs = millis();
  bool wasRunning = false;

  for (;;) {
    vTaskDelay(periodTicks);

    bool running = false, manual = false;
    float target = NAN, manualAmps = 0.0f;
    float kp = 0.0f, ki = 0.0f, kd = 0.0f;
    float currentTemp = NAN;

    if (xSemaphoreTake(dataMutex, portMAX_DELAY) == pdTRUE) {
      running = gHeater.running;
      target = gHeater.targetTemperature;
      manual = gHeater.manualOverride;
      manualAmps = gHeater.manualCurrent;
      kp = gHeater.pidKp;
      ki = gHeater.pidKi;
      kd = gHeater.pidKd;
      currentTemp = latestReading.temperature;
      xSemaphoreGive(dataMutex);
    } else {
      continue;
    }

    uint32_t nowMs = millis();
    float dt = (nowMs - prevTimeMs) / 1000.0f;
    prevTimeMs = nowMs;
    if (dt <= 0.0f) dt = 0.2f;

    float outputCurrent = 0.0f;

    if (running) {
      if (!wasRunning) {
        // Just started: reset the integrator so a stale error term from
        // before doesn't cause an output kick.
        integral = 0.0f;
        prevError = 0.0f;
      }
      if (!isnan(currentTemp) && !isnan(target)) {
        float error = target - currentTemp;
        integral += error * dt;
        float derivative = (error - prevError) / dt;
        prevError = error;
        outputCurrent = kp * error + ki * integral + kd * derivative;
      }
      if (outputCurrent < 0.0f) outputCurrent = 0.0f;
      if (outputCurrent > MAX_CURRENT) outputCurrent = MAX_CURRENT;
    } else if (manual) {
      outputCurrent = manualAmps;
      if (outputCurrent < 0.0f) outputCurrent = 0.0f;
      if (outputCurrent > MAX_CURRENT) outputCurrent = MAX_CURRENT;
    }
    wasRunning = running;

    set_output_current(outputCurrent);

    float measuredVoltage = get_voltage();
    float measuredCurrent = get_current();

    if (xSemaphoreTake(dataMutex, portMAX_DELAY) == pdTRUE) {
      latestHeaterReading.voltage = measuredVoltage;
      latestHeaterReading.current = measuredCurrent;
      latestHeaterReading.outputCurrent = outputCurrent;
      xSemaphoreGive(dataMutex);
    }
  }
}
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

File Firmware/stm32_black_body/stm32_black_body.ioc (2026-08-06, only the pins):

Mcu.UserName=STM32G431RBTx
PA0.GPIO_Label=i_sense_sel2
PA0.Signal=GPIO_Output
PA1.GPIO_Label=i_sense_sel3
PA1.Signal=GPIO_Output
PA11.Signal=USB_DM
PA12.Signal=USB_DP
PA13.Signal=SYS_JTMS-SWDIO
PA14.Signal=SYS_JTCK-SWCLK
PA15.GPIO_Label=SPI3_CS
PA15.Signal=GPIO_Output
PA2.GPIO_Label=hbridge_sel4
PA2.Signal=GPIO_Output
PA3.GPIO_Label=i_sense_sel4
PA3.Signal=GPIO_Output
PA4.GPIO_Label=hbridge_sel3
PA4.Signal=GPIO_Output
PA5.GPIO_Label=hbridge_sel1
PA5.Signal=GPIO_Output
PA6.GPIO_Label=hbridge_sel2
PA6.Signal=GPIO_Output
PA7.GPIO_Label=sel_10na_pos
PA7.Signal=GPIO_Output
PA8.Signal=S_TIM1_CH1
PB0.GPIO_Label=sel_100na_neg
PB0.Signal=GPIO_Output
PB1.GPIO_Label=sel_t_1ma
PB1.Signal=GPIO_Output
PB10.GPIO_Label=sel_10na_neg
PB10.Signal=GPIO_Output
PB12.GPIO_Label=SPI2_CS
PB12.Signal=GPIO_Output
PB13.Signal=SPI2_SCK
PB14.Signal=SPI2_MISO
PB15.Signal=SPI2_MOSI
PB2.GPIO_Label=sel_t_1ua
PB2.Signal=GPIO_Output
PB4.GPIO_Label=sel_v_100ua
PB4.Signal=GPIO_Output
PB5.GPIO_Label=sel_v_1ua
PB5.Signal=GPIO_Output
PB7.GPIO_Label=sel_t_100ua
PB7.Signal=GPIO_Output
PB9.GPIO_Label=sel_t_10ua
PB9.Signal=GPIO_Output
PC0.GPIO_Label=ADC_DRDY
PC0.Signal=GPXTI0
PC1.GPIO_Label=i_source_sel3
PC1.Signal=GPIO_Output
PC10.Signal=SPI3_SCK
PC11.Signal=SPI3_MISO
PC12.Signal=SPI3_MOSI
PC13.GPIO_Label=sel_v_1ma
PC13.Signal=GPIO_Output
PC15-OSC32_OUT.GPIO_Label=i_source_sel4
PC15-OSC32_OUT.Signal=GPIO_Output
PC2.GPIO_Label=i_source_sel2
PC2.Signal=GPIO_Output
PC3.GPIO_Label=i_sense_sel1
PC3.Signal=GPIO_Output
PC4.GPIO_Label=sel_100na_pos
PC4.Signal=GPIO_Output
PC5.GPIO_Label=i_source_sel1
PC5.Signal=GPIO_Output
PC8.Signal=I2C3_SCL
PC9.Signal=I2C3_SDA
PD2.GPIO_Label=sel_v_10ua
PD2.Signal=GPIO_Output
PF0-OSC_IN.Signal=RCC_OSC_IN
PF1-OSC_OUT.Signal=RCC_OSC_OUT

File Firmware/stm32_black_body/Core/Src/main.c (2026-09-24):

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
/* Includes ------------------------------------------------------------------*/
#include "main.h"
#include "Ring_Buffer.h"
#include "stm32g4xx_hal.h"
#include "switches.h"

I2C_HandleTypeDef hi2c3;

SPI_HandleTypeDef hspi2;
SPI_HandleTypeDef hspi3;

TIM_HandleTypeDef htim1;

PCD_HandleTypeDef hpcd_USB_FS;

float volt_scale = 0.0;
float resistance_shift = 0.0;

void SystemClock_Config(void);
static void MX_GPIO_Init(void);
static void MX_USB_PCD_Init(void);
static void MX_SPI2_Init(void);
static void MX_SPI3_Init(void);
static void MX_I2C3_Init(void);
static void MX_TIM1_Init(void);
/* USER CODE BEGIN 0 */

ring_buffer voltage_buff;
ring_buffer current_buff;
ADS131M04 spi_params;
volatile uint8_t adc_flag = 0;
/* USER CODE END 0 */

/**
  * @brief  The application entry point.
  * @retval int
  */
int main(void)
{

  /* MCU Configuration--------------------------------------------------------*/

  /* Reset of all peripherals, Initializes the Flash interface and the Systick. */
  HAL_Init();

  /* Configure the system clock */
  SystemClock_Config();

  /* Initialize all configured peripherals */
  MX_GPIO_Init();
  MX_USB_PCD_Init();
  MX_SPI2_Init();
  MX_SPI3_Init();
  MX_I2C3_Init();
  MX_TIM1_Init();
  /* Infinite loop */
  /* USER CODE BEGIN WHILE */

  // Config External ADC read
  ADS131M04 ADS_hdev;
  ADS_hdev.clk_channel = TIM_CHANNEL_1;
  ADS_hdev.clk_htim = &htim1;
  ADS_hdev.cs_port = SPI3_CS_GPIO_Port;
  ADS_hdev.cs_pin = SPI3_CS_Pin;
  ADS_hdev.hspi = &hspi3;

  // Initilize spi_data struct
  Sensor_Data spi_data;

  // Change current parameters and change spi_data struct
  change_current(cur_100ua, right, &spi_data);
  HAL_Delay(1000);
  // Initilise external adc
  ADS131M04_Init(&ADS_hdev);
 
  // ADC buffer
  int32_t reg_data[4] = {0};

  // Ring buffer
  ring_buffer v_buff;
  ring_buffer i_buff; 
  ringBufferInit(&v_buff);
  ringBufferInit(&i_buff);
  // Debugging counter
  //int count = 0;
  while (1)
  {
    // Read adc data once drdy interupt fires
    if (adc_flag == 1){
      ADS131M04_ADC_Read(&ADS_hdev, reg_data);
      // Get shunt resistance value
      float shunt_resistance = 0;
      switch(spi_data.shunt_resistor){
        
        case 0:
          shunt_resistance = 3.2;
          break;
        case 1:
          shunt_resistance = 8.2;
          break;
        case 2:
          shunt_resistance = 503;
          break;
        case 3:
          shunt_resistance = 33200;
          break;
        default:
          shunt_resistance = 1;
          break;

      }

      // Save data to send over spi

      // 6 comes from adc max range of 1.2 * gain of 200 converted to mv
      float raw_voltage = float_abs(map(reg_data[1], -8388608, 8388607, -6.0, 6.0));

      // 6 comes from adc max range of 1.2 * gain of 200 converted to mv
      // Works on the principle of I = V/R using the shunt resistance
      // Multiply by 1000 to convert to uA
      float raw_current = float_abs(map(reg_data[0], -8388608, 8388607, -6.0, 6.0)) / shunt_resistance * 1000;

      // Smooth minor ADC noise with a 20-sample rolling average before
      // sending over SPI (resistance is then derived from the averaged
      // V/I so it inherits the same smoothing).
      spi_data.voltage = (float)bufferAddAverage((double)raw_voltage, &v_buff);
      spi_data.current = (float)bufferAddAverage((double)raw_current, &i_buff);
      spi_data.resistance = (spi_data.voltage / spi_data.current * 1000 * volt_scale) + resistance_shift;

      // Reset drdy flag
      external_interface_send(&spi_data, &hspi2);
      adc_flag = 0;
    }

    if (autoset_current(&spi_data)){
      // Current source (and therefore the voltage/current scale) just
      // changed: drop the old samples so the rolling average doesn't blend
      // readings taken at two different ranges.
      ringBufferInit(&v_buff);
      ringBufferInit(&i_buff);
    }

    //Debugging
    //if (count >= 200) {
      //if (spi_data.cur_source == 5) change_current(cur_100ua, right, &spi_data);
      //else if (spi_data.cur_source == 4) change_current(cur_1ma, right, &spi_data);
      //count = 0;
    //}
    //count++;
    //End debugging
    /* USER CODE END WHILE */

    /* USER CODE BEGIN 3 */
  }
  /* USER CODE END 3 */
}

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
/* USER CODE BEGIN 4 */
void HAL_GPIO_EXTI_Callback(uint16_t GPIO_Pin){
  if (GPIO_Pin == ADC_DRDY_Pin){
    adc_flag = 1;
  } else {
    __NOP();
  }
}


void set_shunt(current source_current, Sensor_Data *data){
  // Set shunt based on current source
  cur_resistor shunt_resistor = 0;
  if (source_current < 2){
    shunt_resistor = _33k2;
  }
  else if (source_current < 4){
    shunt_resistor = _500;
  }
  else if (source_current < 5){
    shunt_resistor = _5;
  }
  else if (source_current < 6){
    shunt_resistor = none;
  } 
  else {
    shunt_resistor = disable;
  }
  current_measurement_resistor(shunt_resistor);
  
  // Update shunt value sent to esp32
  data->shunt_resistor = shunt_resistor;
}

int autoset_current(Sensor_Data *spi_data){
  int changed = 0;
  switch((int)spi_data->cur_source){
    //case 0:
      //if (spi_data->voltage < 0.06){
        //current_source(cur_100na);
        //spi_data->cur_source = cur_100na;
        //HAL_Delay(100);
      //}
      //break;
    //case 1:
      //if (spi_data->voltage < 0.2){
        //current_source(cur_1ua);
        //spi_data->cur_source = cur_1ua;
        //HAL_Delay(100);
      //}
      //else if (spi_data->voltage > 0.8){
        //current_source(cur_10na);
        //spi_data->cur_source = cur_10na;
        //HAL_Delay(100);
      //}
      //break;
    //case 2:
      //if (spi_data->voltage < 0.5){
        //current_source(cur_10ua);
        //spi_data->cur_source = cur_10ua;
        //HAL_Delay(100);
      //}
      //else if (spi_data->voltage > 3){
        //current_source(cur_100na);
        //spi_data->cur_source = cur_100na;
        //HAL_Delay(100);
      //}
      //break;
    case 3:
      if (spi_data->voltage < 0.4){
        current_source(cur_100ua, &volt_scale, &resistance_shift);
        spi_data->cur_source = cur_100ua;
        changed = 1;
      }
      //else if (spi_data->voltage > 5.0){
        //current_source(cur_1ua);
        //spi_data->cur_source = cur_1ua;
        //HAL_Delay(100);
      //}
      break;
    case 4:
      if (spi_data->voltage < 0.4){
        current_source(cur_1ma, &volt_scale, &resistance_shift);
        spi_data->cur_source = cur_1ma;
        changed = 1;
      }
      else if (spi_data->voltage > 5.0){
        current_source(cur_10ua, &volt_scale, &resistance_shift);
        spi_data->cur_source = cur_10ua;
        changed = 1;
      }
      break;
    case 5:
      if (spi_data->voltage > 5.0){
        current_source(cur_100ua, &volt_scale, &resistance_shift);
        spi_data->cur_source = cur_100ua;
        HAL_Delay(100);
        changed = 1;
      }
      break;
  }
  if (changed == 1){
    set_shunt(spi_data->cur_source, spi_data);
  }
  return changed;
}
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

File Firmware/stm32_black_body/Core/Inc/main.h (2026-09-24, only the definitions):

#define sel_v_1ma_Pin GPIO_PIN_13
#define sel_v_1ma_GPIO_Port GPIOC
#define i_source_sel4_Pin GPIO_PIN_15
#define i_source_sel4_GPIO_Port GPIOC
#define ADC_DRDY_Pin GPIO_PIN_0
#define ADC_DRDY_GPIO_Port GPIOC
#define ADC_DRDY_EXTI_IRQn EXTI0_IRQn
#define i_source_sel3_Pin GPIO_PIN_1
#define i_source_sel3_GPIO_Port GPIOC
#define i_source_sel2_Pin GPIO_PIN_2
#define i_source_sel2_GPIO_Port GPIOC
#define i_sense_sel1_Pin GPIO_PIN_3
#define i_sense_sel1_GPIO_Port GPIOC
#define i_sense_sel2_Pin GPIO_PIN_0
#define i_sense_sel2_GPIO_Port GPIOA
#define i_sense_sel3_Pin GPIO_PIN_1
#define i_sense_sel3_GPIO_Port GPIOA
#define hbridge_sel4_Pin GPIO_PIN_2
#define hbridge_sel4_GPIO_Port GPIOA
#define i_sense_sel4_Pin GPIO_PIN_3
#define i_sense_sel4_GPIO_Port GPIOA
#define hbridge_sel3_Pin GPIO_PIN_4
#define hbridge_sel3_GPIO_Port GPIOA
#define hbridge_sel1_Pin GPIO_PIN_5
#define hbridge_sel1_GPIO_Port GPIOA
#define hbridge_sel2_Pin GPIO_PIN_6
#define hbridge_sel2_GPIO_Port GPIOA
#define sel_10na_pos_Pin GPIO_PIN_7
#define sel_10na_pos_GPIO_Port GPIOA
#define sel_100na_pos_Pin GPIO_PIN_4
#define sel_100na_pos_GPIO_Port GPIOC
#define i_source_sel1_Pin GPIO_PIN_5
#define i_source_sel1_GPIO_Port GPIOC
#define sel_100na_neg_Pin GPIO_PIN_0
#define sel_100na_neg_GPIO_Port GPIOB
#define sel_t_1ma_Pin GPIO_PIN_1
#define sel_t_1ma_GPIO_Port GPIOB
#define sel_t_1ua_Pin GPIO_PIN_2
#define sel_t_1ua_GPIO_Port GPIOB
#define sel_10na_neg_Pin GPIO_PIN_10
#define sel_10na_neg_GPIO_Port GPIOB
#define SPI2_CS_Pin GPIO_PIN_12
#define SPI2_CS_GPIO_Port GPIOB
#define SPI3_CS_Pin GPIO_PIN_15
#define SPI3_CS_GPIO_Port GPIOA
#define sel_v_10ua_Pin GPIO_PIN_2
#define sel_v_10ua_GPIO_Port GPIOD
#define sel_v_100ua_Pin GPIO_PIN_4
#define sel_v_100ua_GPIO_Port GPIOB
#define sel_v_1ua_Pin GPIO_PIN_5
#define sel_v_1ua_GPIO_Port GPIOB
#define sel_t_100ua_Pin GPIO_PIN_7
#define sel_t_100ua_GPIO_Port GPIOB
#define sel_t_10ua_Pin GPIO_PIN_9
#define sel_t_10ua_GPIO_Port GPIOB

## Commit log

2026-05-12 Finished base schematic, missing thermal sensor
    [BLACK BODY SIM.DSN, Black_Body_Heater_Control.kicad_pcb, Black_Body_Heater_Control.kicad_sch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]
2026-05-13 Documentation and file organization
    [BLACK BODY SIM.DSN]
2026-05-13 Buck spice file not working, created new pcb
    [BLACK BODY SIM.DSN, Black_Body_Heater_Control.kicad_sch, Black_Body_Temperature_Sensor_PCB.kicad_pcb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]
2026-05-20 Current source simulations
    [BOM.xlsx, PSPICE_BUCK.DSN, Temperature vs Voltage.xlsx]
2026-05-26 current source simulation, pcb 2->1 switches
    [Black_Body_Temperature_Sensor_PCB.kicad_sch, V&I_sense.kicad_sch, micrcontroller.kicad_sch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]
2026-05-26 temp sensor pcb progress
    [Black_Body_Temperature_Sensor_PCB.kicad_sch, micrcontroller.kicad_sch, nA_current.kicad_sch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]
2026-05-28 power simulation
    [BLACK BODY SIM.DSN, BOM.xlsx, Black_Body_Heater_Control.kicad_pcb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]
2026-06-02 Schematic ready for review
    [Black_Body_Temperature_Sensor_PCB.kicad_sch, Temperature vs Voltage.xlsx, V&I_sense.kicad_sch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]
2026-06-03 Temperature Sensor Schematic Done, awaiting review
    [Black_Body_Temperature_Sensor_PCB.kicad_sch, V&I_sense.kicad_sch, micrcontroller.kicad_sch]
2026-06-05 Heater PCB done (to review)
    [Black_Body_Heater_Control.kicad_pcb, Black_Body_Heater_Control.kicad_sch, ESP32.kicad_sch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]
2026-06-05 Updating ESP32 pcb documentation
2026-06-05 Updating silkscreen
    [Black_Body_Heater_Control.kicad_pcb]
2026-06-08 Temp sensor schematic done
    [Black_Body_Temperature_Sensor_PCB.kicad_sch, ESP32.kicad_sch, V&I_sense.kicad_sch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]
2026-06-10 temp pcb analog layout done
    [Black_Body_Temperature_Sensor_PCB.kicad_pcb, Black_Body_Temperature_Sensor_PCB.kicad_sch, V&I_sense.kicad_sch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]
2026-06-10 Digital section done
    [Black_Body_Temperature_Sensor_PCB.kicad_pcb, V&I_sense.kicad_sch, micrcontroller.kicad_sch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]
2026-06-12 Complete except for recommended changes
    [Black_Body_Heater_Control.kicad_pcb, Black_Body_Temperature_Sensor_PCB.kicad_pcb, V&I_sense.kicad_sch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]
2026-06-15 Heater switched from pwm to vccs
    [Black_Body_Heater_Control.kicad_pcb, Black_Body_Heater_Control.kicad_sch, Black_Body_Temperature_Sensor_PCB.kicad_pcb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]
2026-06-16 heater ready to order
    [Black_Body_Heater_Control.kicad_pcb, ESP32.kicad_sch, black_body_heater_rev0_bom.csv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]
2026-06-18 Temp probe bom done
    [Black_Body_Heater_Control.kicad_pcb, Black_Body_Temperature_Sensor_PCB.kicad_pcb, Black_Body_temperature_sensor_rev0_bom.csv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]
2026-06-20 Designs finished - order placed
    [BOM.xlsx, Black_Body_Heater_Control.kicad_pcb, Black_Body_Temperature_Sensor_PCB.kicad_pcb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]
2026-06-23 Documentation and reorganization
    [BLACK BODY SIM.DSN, PSPICE_BUCK.DSN, Temperature vs Voltage.xlsx]
2026-07-07 pcb's assembled, test code writen
    [Black_Body_Heater_Control.kicad_pcb]
2026-07-16 Minor rev.1 pcb changes. Firmware progress
    [BOM.xlsx, Black_Body_Temperature_Sensor_PCB.kicad_pcb, power_periferals.kicad_sch]
2026-07-18 Writing ADC/DAC library
2026-07-22 ESP32 website works, stm32 adc lib doesn't
    [main.c, main.cpp, main.h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]
2026-08-06 Buck converter doesn't work, firmware missing some ui stuff
    [.step]
2026-08-07 Minor pcb changes
    [Black_Body_Heater_Control.kicad_pcb, power_periferals.kicad_sch]
2026-08-08 Required Schematic changes made
    [Black_Body_Heater_Control.kicad_pcb, Black_Body_Heater_Control.kicad_sch, ESP32.kicad_sch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]
2026-08-19 Changing buck on heater pcb
    [Black_Body_Heater_Control.kicad_pcb, Black_Body_Heater_Control.kicad_sch, ESP32.kicad_sch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]
2026-08-25 Heater control rev 1 ordered
    [Black_Body_Heater_Control.kicad_pcb, Black_Body_Temperature_Sensor_PCB.kicad_pcb, black_body_heater_rev1_bom.csv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]
2026-09-17 minor firmware changes, adding pcb schematic pdf
2026-09-17 adding pcb layer plot
2026-09-17 Adding schematic back
2026-09-21 SPI communication not working for some reason
    [Black_Body_Temperature_Sensor_PCB.kicad_pcb]
2026-09-23 Firmware working, calibration needed
2026-09-24 Everything working, resistance measurement tuned
2026-09-24 Update README with initial power-up instructions
    Added recommendation for resistor connection during initial power-up to ensure sensor integrity after delivery.

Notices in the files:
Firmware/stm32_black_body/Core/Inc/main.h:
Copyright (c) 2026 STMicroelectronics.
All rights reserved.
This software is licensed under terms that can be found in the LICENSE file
